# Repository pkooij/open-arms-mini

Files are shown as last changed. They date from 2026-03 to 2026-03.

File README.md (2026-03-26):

# Open Arms Mini

**Small, low-inertia leader arms for robot teleoperation**

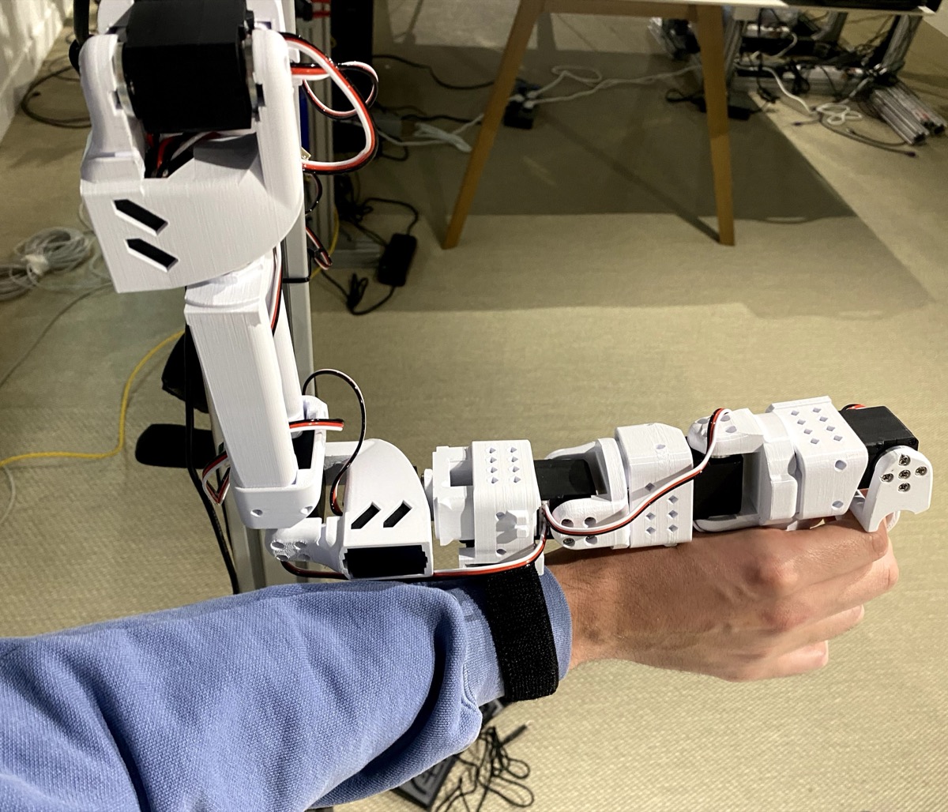
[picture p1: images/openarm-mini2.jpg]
Open Arms Mini with wrist strap


---

## What is Open Arms Mini?

Open Arms Mini is a compact, Feetech-based, 3D-printed leader arm for robot teleoperation. It has 7 DOF with human-like kinematics — 3 shoulder joints, 1 elbow, 1 forearm rotation, and 2 wrist joints — plus a gripper. Designed to be paired with the Open Arms follower arm and integrates with [LeRobot](https://github.com/huggingface/lerobot) as the `openarm_mini` teleoperator.

- **Low inertia** — quick, deliberate motions for precision tasks like cloth folding
- **Arm-length agnostic** — wrist-grip design works for teleoperators of any height
- **Affordable** — ~150 EUR per arm, ~300 EUR for a pair

### The wrist strap

The wrist strap makes a big difference for wrist roll precision — without it the hand tends to slip. Highly recommended.

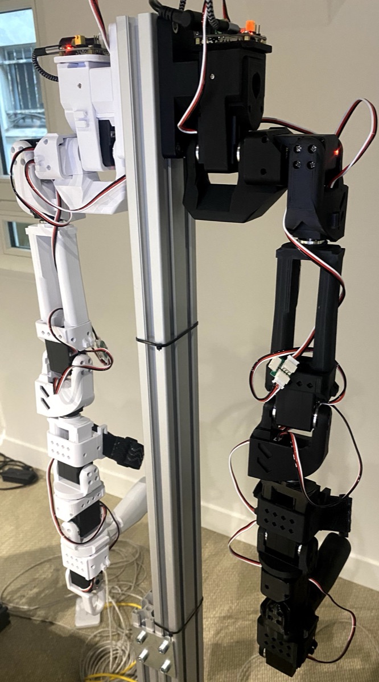
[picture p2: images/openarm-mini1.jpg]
Open Arms Mini paired with follower arm


---

## Bill of Materials

See [BOM.md](BOM.md) for full details. **~150 EUR per arm / ~300 EUR for a pair** (excl. filament and screws).

---

## 3D Printing

| Setting | Recommendation |
|---|---|
| Material | PLA or PETG |
| Layer height | 0.2 mm |
| Infill | 20–40% |
| Supports | Yes, where needed |
| Nozzle | 0.4 mm |

STL files: [`STL/`](STL/) — STEP files (for modification): [`STEP/`](STEP/)

Quantities are for a **complete pair (left + right arm)**. Universal parts (no L/R) = 2, gripper L/R parts = 1 each, WaveShare plate shared = 1. **Total: 32 parts for a pair** (16 per arm).

| File | Description | Qty (pair) |
|---|---|---|
| `J1 v5.stl` | Shoulder pan joint | 2 |
| `J1_holder v1.stl` | Shoulder pan motor holder | 2 |
| `J2 v2.stl` | Shoulder lift joint | 2 |
| `J2_holder v1.stl` | Shoulder lift motor holder | 2 |
| `J3 v2.stl` | Shoulder roll joint | 2 |
| `J4 v3.stl` | Elbow joint | 2 |
| `J4_holder v1.stl` | Elbow motor holder | 2 |
| `J5 v4.stl` | Forearm rotation joint | 2 |
| `J6 v6.stl` | Wrist flex joint | 2 |
| `J6 holder with strap v4.stl` | Wrist strap holder | 2 |
| `J7 v4.stl` | Wrist roll joint | 2 |
| `J7_holder v1.stl` | Wrist roll motor holder | 2 |
| `J Handle v12.stl` | Main handle | 2 |
| `J8 L v4.stl` | Gripper claw — left | 1 |
| `J8 R v10.stl` | Gripper claw — right | 1 |
| `J8 holder L v2.stl` | Gripper claw holder — left | 1 |
| `J8 holder R v6.stl` | Gripper claw holder — right | 1 |
| `J trigger L v2.stl` | Gripper trigger — left | 1 |
| `J trigger R v2.stl` | Gripper trigger — right | 1 |
| `WaveShare_Mounting_Plate_SO101 v1.stl` | WaveShare controller mounting plate (shared) | 1 |
| `arducam_holder v6.stl` | Arducam camera mount (optional) | — |

---

## Assembly

**Per arm:** 8× Feetech STS3215-C046 servo (7.4 V, 1:147), 1× Waveshare Serial Bus Servo Driver Board, M2×6 and M3×6 screws (~35 each), 8× 3-pin servo cables, 7.5 V power supply, 1× velcro wrist strap (~25 mm).

### Motor IDs

Configure motors before assembly (easier when not yet installed):

```bash
lerobot-setup-motors \
    --teleop.type=openarm_mini \
    --teleop.port=/dev/tty.usbmodem575E0031751
```

| ID | Joint | Part |
|---|---|---|
| 1 | Shoulder Pan | J1 |
| 2 | Shoulder Lift | J2 |
| 3 | Shoulder Roll | J3 |
| 4 | Elbow Flex | J4 |
| 5 | Forearm Rotation | J5 |
| 6 | Wrist Flex | J6 |
| 7 | Wrist Roll | J7 |
| 8 | Gripper | J8 L/R |

> **Joint swap note:** Wrist flex (6) and wrist roll (7) are deliberately swapped in software relative to the follower arm — this feels more natural given how the human wrist moves. Handled automatically by the `openarm_mini` driver.

### Assembly order

1. **Shoulder Pan (J1)** — Insert motor 1, secure with 4× M2×6. Attach J1_holder with 2× M2×6. Install motor horns, secure top horn with M3×6.
2. **Shoulder Lift (J2)** — Slide motor 2 in, fasten with 4× M2×6. Attach motor horns. Connect J2 to J1 with 4× M3×6 each side.
3. **Shoulder Roll (J3)** — Insert motor 3, fasten with 4× M2×6. Attach motor horns. Connect J3 to J2 with 4× M3×6 each side.
4. **Elbow (J4)** — Slide J4_holder over J3. Insert motor 4, fasten with 4× M2×6. Attach motor horns.
5. **Forearm Rotation (J5)** — Insert motor 5, secure with 2× M2×6. Install one motor horn. Secure J5 to motor 4 with 4× M3×6 each side.
6. **Wrist Flex (J6)** — Attach J6 to motor 5 horn with 4× M3×6. Insert motor 6, secure with 2× M2×6. Attach motor horns.
7. **Wrist Roll (J7)** — Attach J7 to motor 6 with J7_holder. Insert motor 7, fasten with 4× M2×6.
8. **Gripper** — Insert motor 8 into J8 holders. Attach J8 L/R claws with 4× M3×6 each side. Attach triggers.
9. **Handle & strap** — Attach J Handle. Mount J6 holder with strap at the wrist. Thread velcro strap and adjust for a snug fit.
10. **Controller board** — Mount Waveshare board on WaveShare_Mounting_Plate. Daisy-chain motors 1→8.

---

## LeRobot Integration

Natively integrated into [LeRobot](https://github.com/huggingface/lerobot) — source: [`lerobot/teleoperators/openarm_mini`](https://github.com/huggingface/lerobot/tree/main/src/lerobot/teleoperators/openarm_mini).

```bash
pip install lerobot[feetech]
```

```bash
# Find port
lerobot-find-port

# Calibrate
lerobot-calibrate \
    --teleop.type=openarm_mini \
    --teleop.port=/dev/tty.usbmodem575E0031751 \
    --teleop.id=my_mini_leader_arm

# Teleoperate
lerobot-teleoperate \
    --teleop.type=openarm_mini \
    --teleop.port=/dev/tty.usbmodem575E0031751 \
    --teleop.id=my_mini_leader_arm
```

---

## License

Hardware designs released under [Apache 2.0](LICENSE). Based on the [SO-ARM100](https://github.com/TheRobotStudio/SO-ARM100) design.

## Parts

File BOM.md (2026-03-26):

# Bill of Materials — Open Arms Mini

Quantities and prices are given **per arm** and **for a pair (left + right)**.

**Approximate total cost: ~150 EUR per arm / ~300 EUR for a pair** (excluding 3D printing materials and screws)

---

## Electronics

| Component | Qty (per arm) | Qty (pair) | Unit price | Total (pair) | Link |
|---|---|---|---|---|---|
| Feetech STS3215-C046 servo (7.4 V, 1:147) | 8 | 16 | ~15 EUR | ~240 EUR | [WowRobo](https://shop.wowrobo.com/products/feetech-sts3215-c046-servo-7-4v-14-4kg-1-147-servo-for-so-arm101) |
| Waveshare Serial Bus Servo Driver Board | 1 | 2 | ~10 EUR | ~20 EUR | [Waveshare](https://www.waveshare.com/bus-servo-adapter-a.htm) |
| 7.5 V DC power supply (2 A min.) | 1 | 2 | ~12 EUR | ~24 EUR | [Amazon FR](https://www.amazon.fr/-/en/dp/B0788C3KFY) |
| USB-A to USB-C cable | 1 | 2 | ~3 EUR | ~6 EUR | Any |

## Wrist Strap

| Component | Qty (per arm) | Qty (pair) | Unit price | Total (pair) | Link |
|---|---|---|---|---|---|
| Elastic velcro wrist strap (~25 mm wide) | 1 | 2 | ~5 EUR | ~10 EUR | [Amazon FR](https://www.amazon.fr/-/en/Elastic-Straps-Fasteners-Anti-Slip-Organizing/dp/B0CH9LX6KZ) |

## Fasteners

| Component | Qty (per arm) | Qty (pair) | Notes |
|---|---|---|---|
| M2×6 mm screws | ~35 | ~70 | Motor mounting |
| M3×6 mm screws | ~35 | ~70 | Structural joints |
| M3×6 mm horn screws | 8 | 16 | One per motor — usually included with motors |
| 3-pin servo cables (150–200 mm) | 8 | 16 | Daisy-chain between motors |

## 3D Printing

| Material | Per arm | Pair |
|---|---|---|
| PLA or PETG filament | ~150–200 g | ~300–400 g |

Approximate filament cost: ~5 EUR per arm / ~10 EUR for a pair at standard PLA prices.

---

## Total estimate

| Category | Per arm | Pair |
|---|---|---|
| Servos | ~120 EUR | ~240 EUR |
| Electronics | ~22 EUR | ~44 EUR |
| Wrist strap | ~5 EUR | ~10 EUR |
| Filament | ~5 EUR | ~10 EUR |
| Screws & cables | ~5 EUR | ~10 EUR |
| **Total** | **~157 EUR** | **~314 EUR** |

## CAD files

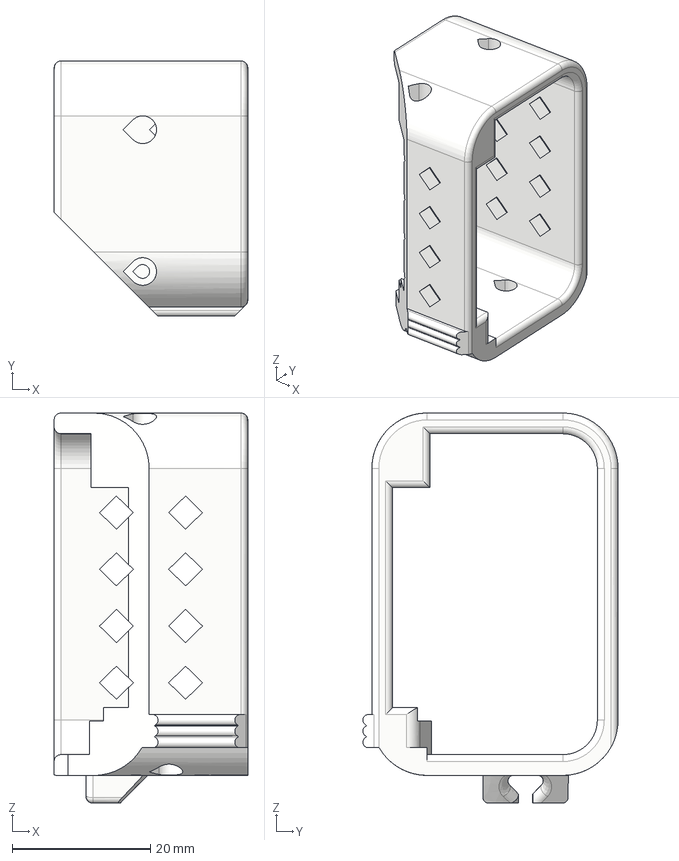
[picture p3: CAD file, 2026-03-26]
STEP/J7_holder.step
28.0 x 36.9 x 56.4 mm
Wiring_holder v1
Wiring_holder v1 (1)

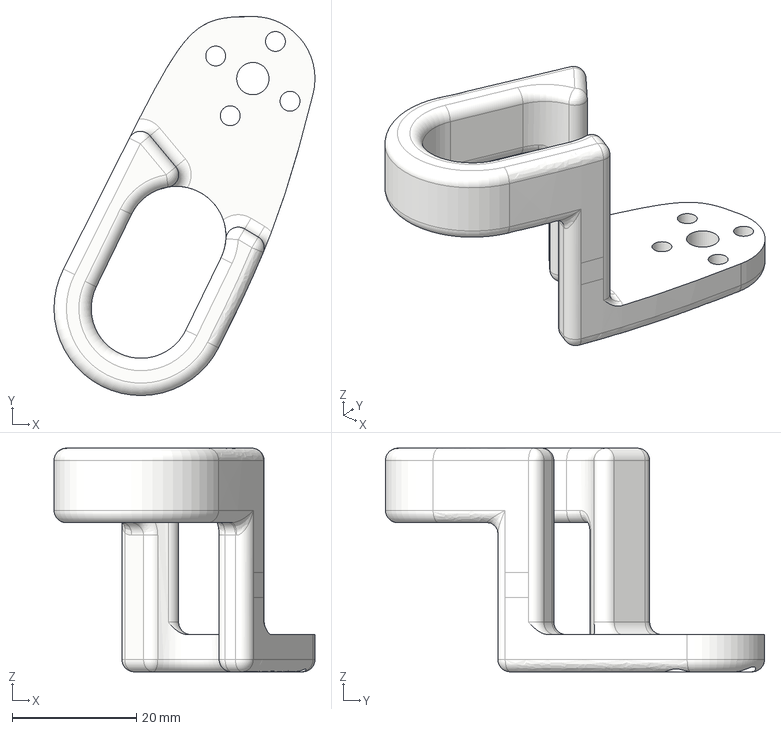
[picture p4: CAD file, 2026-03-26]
STEP/J trigger L.step
42.0 x 61.0 x 36.0 mm

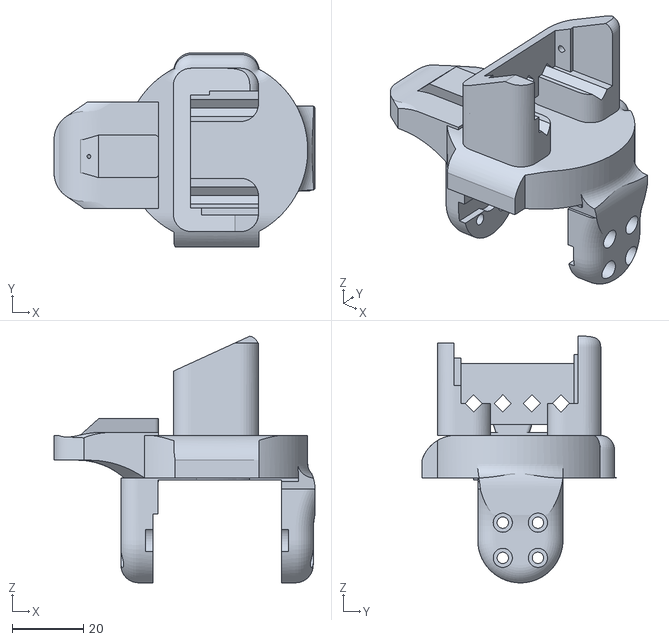
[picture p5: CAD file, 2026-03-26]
STL/J8 L v4.stl
73.5 x 54.7 x 69.5

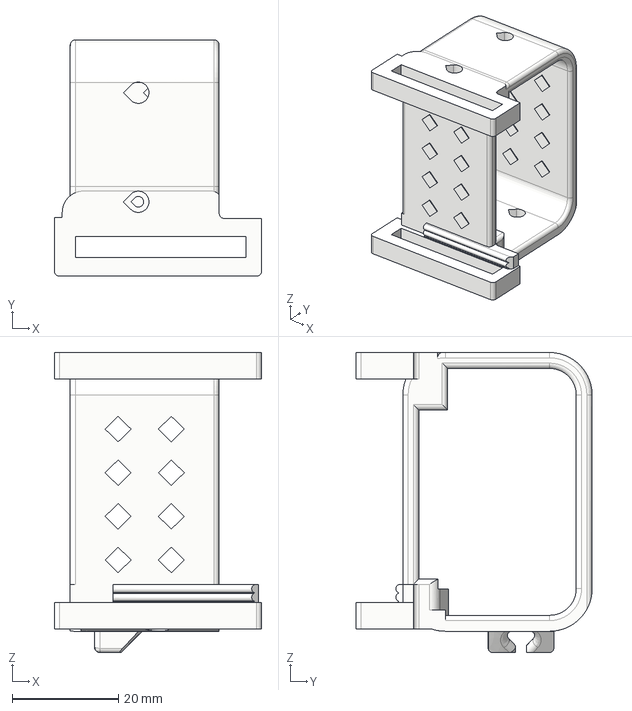
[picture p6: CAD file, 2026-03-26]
STEP/J6 holder with strap.step
39.0 x 44.4 x 56.4 mm
Wiring_holder v1
Wiring_holder v1 (1)

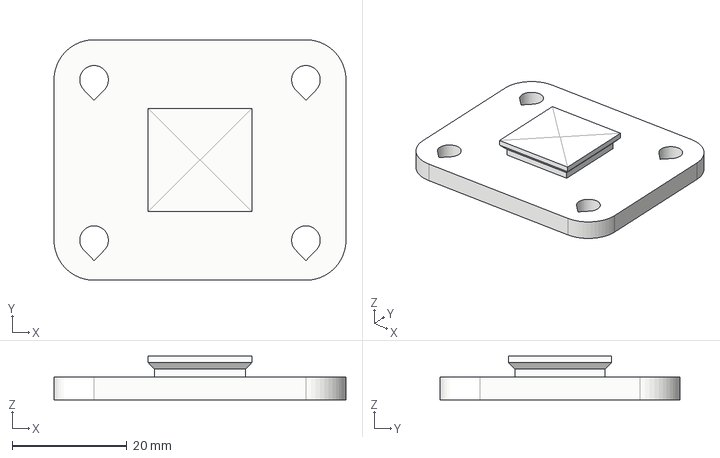
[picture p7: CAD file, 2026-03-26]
STEP/WaveShare_Mounting_Plate_SO101.step
51.0 x 42.0 x 7.60 mm

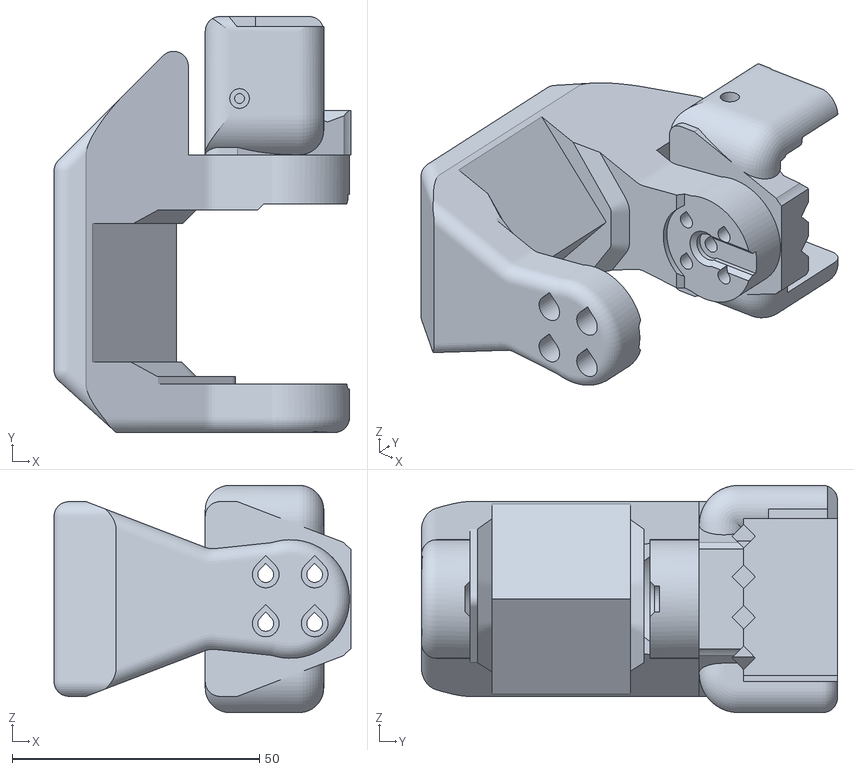
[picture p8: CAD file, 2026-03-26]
STL/J2 v2.stl
60.1 x 84.2 x 46.0

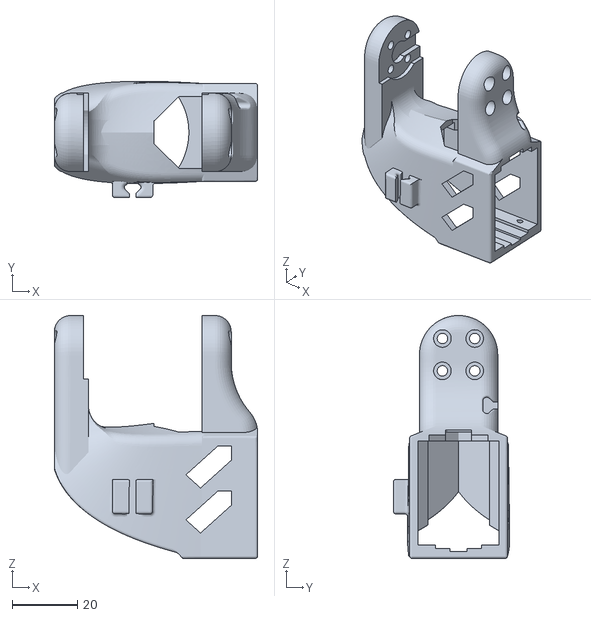
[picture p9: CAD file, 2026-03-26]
STL/J3 v2.stl
62.3 x 35.7 x 74.4

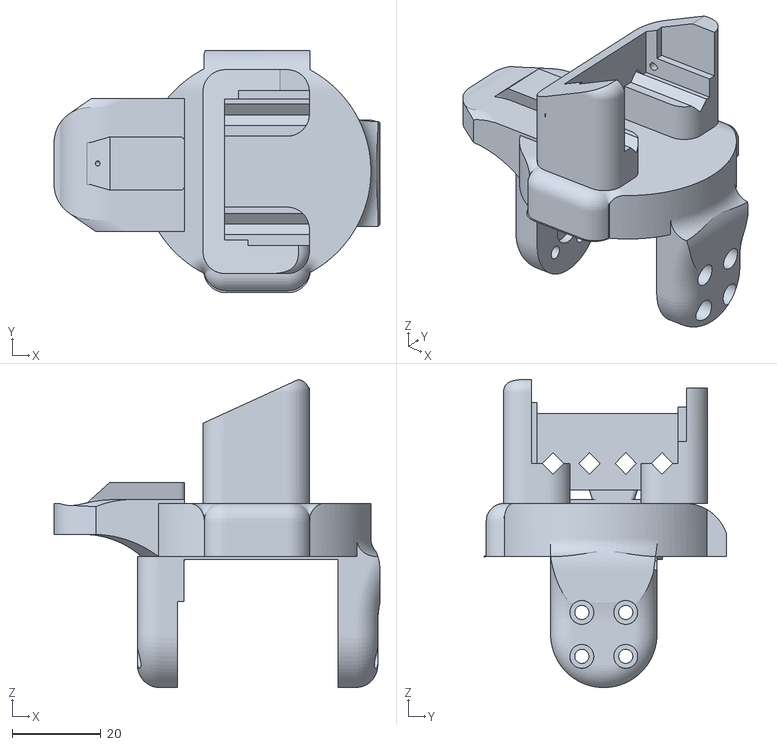
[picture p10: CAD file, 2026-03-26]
STL/J8 R v10.stl
73.5 x 54.7 x 69.5

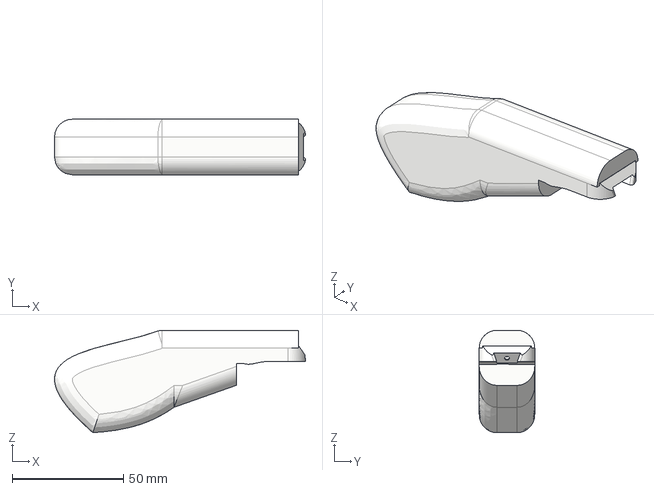
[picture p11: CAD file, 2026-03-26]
STEP/J Handle.step
113.0 x 25.0 x 46.1 mm

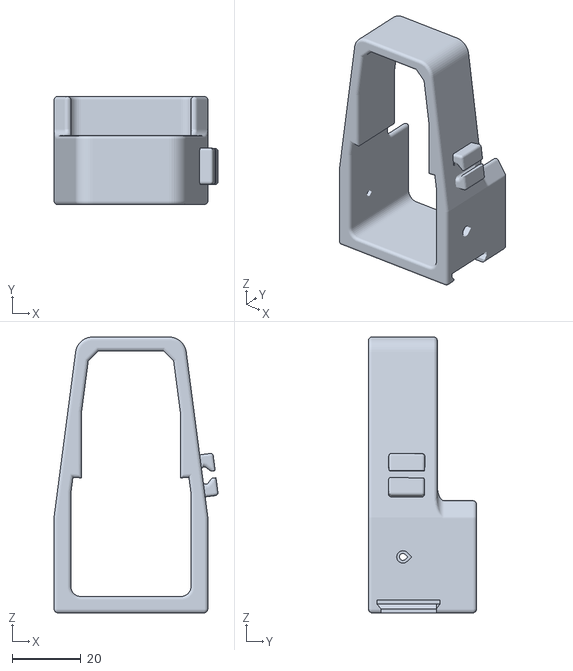
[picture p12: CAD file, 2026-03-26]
STL/J1_holder v1.stl
47.6 x 31.4 x 80.2

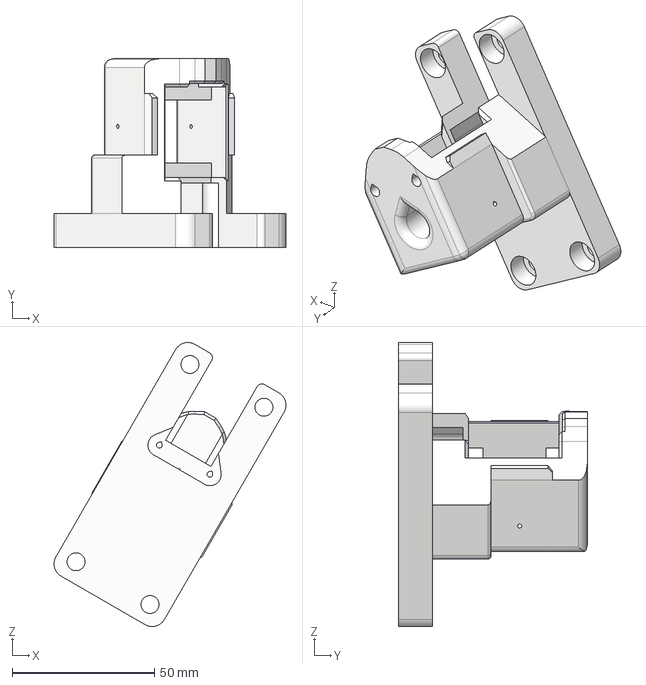
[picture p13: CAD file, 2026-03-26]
STEP/J1.step
81.4 x 66.5 x 99.7 mm

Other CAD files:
STL/J2_holder v1.stl
STL/J6 holder with strap v4.stl
STL/J4_holder v1.stl
STEP/J8 holder L.step
STEP/J trigger R.step
STEP/J8 L.step
STL/J1 v5.stl
STEP/J1_holder.step
STEP/J2.step
STEP/J2_holder.step
STEP/J3.step
STEP/J4.step
STEP/J4_holder.step
STEP/J5.step
STEP/J6.step
STEP/J7.step
STEP/J8 R.step
STEP/J8 holder R.step
STL/J Handle v12.stl
STL/J trigger L v2.stl
STL/J trigger R v2.stl
STL/J4 v3.stl
STL/J5 v4.stl
STL/J6 v6.stl
STL/J7 v4.stl
STL/J7_holder v1.stl
STL/J8 holder L v2.stl
STL/J8 holder R v6.stl
STL/WaveShare_Mounting_Plate_SO101 v1.stl
STL/arducam_holder v6.stl

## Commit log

2026-03-26 init: Open Arms Mini repo with STL/STEP files, README, and BOM
    6-DOF Feetech-based mini leader arm for SO-101 teleoperation.
    Includes all 21 STL parts, 20 STEP source files, full assembly
    instructions, BOM (~120 EUR/arm), and LeRobot integration guide.
    [J Handle v12.stl, J Handle.step, J trigger L v2.stl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]
2026-03-26 docs: update to 7DOF+gripper (8 motors), fix motor IDs, openarm_mini commands
2026-03-26 docs: add Open Arms follower pairing note and joint swap explanation
2026-03-26 docs: update parts list and BOM for left+right pair, universal parts qty=2
2026-03-26 docs: fix parts list total to 32 for a pair, WaveShare plate shared (qty=1)
